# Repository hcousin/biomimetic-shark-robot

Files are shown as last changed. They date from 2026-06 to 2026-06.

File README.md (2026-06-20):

# Biomimetic Shark Robot — Hybrid Passive Tail Edition

**Naturgetreuer Haifisch-Roboter mit exzentrischer Nockenwelle (J1/J2 aktiv) + passiven TPU-Federgelenken (J3/J4)**

> 🌿 **Branch:** `dev/hybrid-passive-tail` — Hybrid-Design
> 📦 **main:** 4× aktive Gelenke (älteres Design)

---

## 📋 Projektübersicht

Ein biomimetischer Unterwasser-Roboter in Haiform (60 cm Länge), der mit **nur 1 Brushless-Motor** eine natürliche Schwimmbewegung erzeugt. Die kurze exzentrische Nockenwelle (60mm) treibt J1+J2 aktiv an — J3+J4 sind passive TPU-Federgelenke, die durch Trägheit und Wasserkräfte natürlich nachschwingen. Biologisch authentischer als 4× aktive Gelenke!

**Kernfeatures:**
- ✅ Hybrid-Antrieb: J1/J2 aktiv (Nockenwelle) + J3/J4 passiv (TPU-Feder)
- ✅ 1× Brushless Motor KV=900 (effizient, wasserdicht)
- ✅ Kurze Nockenwelle 60mm (günstiger, kompakter)
- ✅ Progressive Amplituden: J1 ±5.7° → J2 ±6.9° → J3 ~±10° → J4 ~±15°
- ✅ Passive Resonanz: J3 ≈ 1.0 Hz, J4 ≈ 0.8 Hz
- ✅ Tiefenregelung (PID + Ballast)
- ✅ IMU-Feedback (Brustflossen-Pitch)
- ✅ WiFi + Serial-Steuerung
- ✅ Fusion 360 Workflow: Haifisch-Körperhülle + Verbindungsflansch

---

## 📁 Dateistruktur

```
biomimetic-shark-robot/
├── README.md                                   ← Du bist hier
├── firmware/
│   ├── shark_single_motor_firmware.ino         ← ESP32 Hauptcode
│   └── nocke_kinematik.py                      ← Hybrid-Kinematik-Simulator
├── mechanics/
│   ├── hybrid_passive_tail_mechanics.md        ← Hybrid-Design Dokumentation ★
│   └── single_motor_mechanics.md               ← Referenz (4× aktiv, älter)
├── hardware/
│   └── bom_complete.csv                        ← Stückliste (Hybrid-Design)
├── cad/
│   ├── body_to_j1_flange.scad                  ← Verbindung Körper → J1 ★
│   ├── tail_link_parametric.scad               ← Gelenk-Flansche J1/J2 ★
│   ├── tpu_joint_j3.scad                       ← Passiver Federblock J3 ★
│   ├── tpu_joint_j4.scad                       ← Passiver Federblock J4 ★
│   ├── tail_link_j1.scad                       ← J1 OpenSCAD (Referenz)
│   ├── body_front.scad                         ← Hauptgehäuse
│   ├── silikon_form_flosse.scad                ← Silikonform Schwanzflosse
│   └── stl/                                    ← Exportierte STL-Dateien
├── docs/
│   ├── 3d_print_structure.md                   ← 3D-Druck Parameter (Hybrid)
│   ├── rf_underwater/rf_physics.md             ← RF-Physik Unterwasser
│   ├── silicone_molding_guide.md               ← Silikonabguss-Anleitung
│   └── strouhal_optimizer.py                   ← Hydrodynamik-Optimierer
├── schematics/
│   └── schaltplan_v2.svg                       ← Schaltplan ESP32
└── LICENSE
```

---

## 🚀 Schnelleinstieg

### Hardware-Voraussetzungen
- ESP32 DevKit v1
- Brushless Outrunner Motor (KV=900) + ESC 20A
- Nockenwelle Edelstahl Ø12×**60mm**, e=3mm (Dreherei ~20 CHF)
- 2× Gelenk-Flansche J1/J2 (PETG, aus `tail_link_parametric.scad`)
- 2× TPU-Federblöcke J3/J4 (TPU 95A + 85A, aus `tpu_joint_j3/j4.scad`)
- Verbindungsflansch Körper→J1 (`body_to_j1_flange.scad`)
- Wasserdichte Sensoren (MS5837, MPU6050)
- LiPo 3S Akku

### Firmware flashen
```bash
# Arduino IDE, Board: ESP32 DevKit v1
# Datei: firmware/shark_single_motor_firmware.ino
```

### Kinematik simulieren
```bash
python3 firmware/nocke_kinematik.py
# Zeigt aktive J1/J2 + passive J3/J4 Simulation über mehrere Zyklen
```

### OpenSCAD → STL (für Fusion 360)
```bash
# 1. OpenSCAD installieren: openscad.org
# 2. Datei öffnen, F6 (Render), dann Export as STL
# 3. In Fusion 360: Insert → Insert Mesh
```

---

## 🔧 Mechanik-Highlights

### Aktive Nockenwelle (J1 + J2)
```
Nockenwelle: Edelstahl Ø12×60mm, e=3mm
Gleitschuhe: 2× (0° und 90° versetzt)

J1 @ 0°:  L=30mm → arcsin(3/30) ≈ ±5.7°  (Kopf-nah)
J2 @ 90°: L=25mm → arcsin(3/25) ≈ ±6.9°  (Vordermitte)
```

### Passive TPU-Gelenke (J3 + J4)
```
J3: TPU 95A, 25% Infill → f_res ≈ 1.0 Hz → ~±10° bei Resonanz
J4: TPU 85A, 20% Infill → f_res ≈ 0.8 Hz → ~±15° bei Resonanz

Federstahl-Einlage 0.3mm empfohlen (verhindert Überdehnung)
```

### Phasenversätze (automatisch, mechanisch)
```
J1: θ₁(t) = 5.7°  · sin(2πf·t)
J2: θ₂(t) = 6.9°  · sin(2πf·t − π/2)
J3: θ₃(t) ≈ 10°   · sin(2πf·t − π)      ← passiv, resonanzverstärkt
J4: θ₄(t) ≈ 15°   · sin(2πf·t − 3π/2)   ← passiv, maximale Amplitude
```

---

## 📊 Performance-Daten

| Throttle | Motor RPM | Nocken Hz | Geschw. est. |
|---|---|---|---|
| 10% | ~1000 | 0.4 Hz | ~0.08 m/s |
| 25% | ~2500 | 1.0 Hz | ~0.22 m/s ← J3 Resonanz! |
| 20% | ~2000 | 0.8 Hz | ~0.18 m/s ← J4 Resonanz! |
| 50% | ~5000 | 2.1 Hz | ~0.44 m/s |

---

## 🛠️ Montage-Reihenfolge

1. **Kurze Nockenwelle** (60mm, Dreherei)
2. **Motor + Getriebe** (unverändert)
3. **Nur 2 Gleitschuhe** @ 0° + 90°
4. **J1 + J2 Flansche** an Zug-Stoß-Stangen
5. **TPU-Blöcke J3 + J4** einkleben (Silikonkleber, 24h)
6. **Verbindungsflansch** (`body_to_j1_flange.scad`) → Fusion 360 anpassen
7. **Elektronik** + Sensoren in Gehäuse
8. **Wassertest** bei 25% Throttle

---

## 🐟 Fusion 360 Workflow (Körperhülle)

```
1. Haifisch-Körper (OBJ) laden von Free3D / GrabCAD
2. Skalieren auf 60cm Länge
3. Schwanz bei ~60% Körperlänge abschneiden (Plane Cut)
4. Shell: 3mm Wandstärke
5. body_to_j1_flange.stl importieren (aus body_to_j1_flange.scad)
6. An Schnittstelle ausrichten → Combine → Join
7. Als STEP exportieren
```

Parameter in `body_to_j1_flange.scad` anpassen:
- `body_w` / `body_h` → Rumpf-Querschnitt an Schnittstelle (in Fusion messen)

---

## 📡 Steuerung

```
WiFi UDP:   "THROTTLE 0.25"  → 25% (J3-Resonanz!)
            "DEPTH 1.0"      → Tauchen auf 1m
            "SURFACE"        → Auftauchen
            "STOP"           → Notfall-Stopp

Serial:     throttle 0.25 | depth 1.0 | status | ?
```

---

## 💰 Kosten (Hybrid-Design)

| Kategorie | Kosten |
|---|---|
| Motor + ESC + Getriebe | ~73 CHF |
| Nockenwelle (kurz, 60mm) | ~20 CHF |
| Elektronik + Sensoren | ~74 CHF |
| 3D-Druck Material | ~66 CHF |
| Silikon + Formen | ~103 CHF |
| Dichtung + Kleinteile | ~65 CHF |
| **TOTAL** | **~458 CHF** |

---

## 📚 Dokumentation

| Datei | Inhalt |
|---|---|
| `mechanics/hybrid_passive_tail_mechanics.md` | Vollständige Mechanik-Spezifikation |
| `docs/3d_print_structure.md` | 3D-Druck Parameter + STL-Liste |
| `docs/silicone_molding_guide.md` | Silikonabguss-Anleitung |
| `firmware/nocke_kinematik.py` | Hybrid-Kinematik-Simulator |
| `docs/rf_underwater/rf_physics.md` | RF-Physik + Tether-Empfehlung |

---

## ⚠️ Sicherheitshinweise

- ⚠️ **Nockenwelle rotiert schnell** — vollständig abdecken!
- ⚠️ **TPU-Blöcke vor Wassertest** auf Klebefestigkeit prüfen
- ⚠️ **Wasserdichtheit prüfen** vor dem Eintauchen (Drucktest)
- ⚠️ **LiPo in feuerfester Box** laden

---

## 📖 Lizenz

MIT License — Frei nutzbar, Änderungen erlaubt, Nennung erforderlich.

---

**Status:** ✅ Hybrid-Design vollständig dokumentiert (Stand: Juni 2026)
**Branch:** `dev/hybrid-passive-tail` | PR #2 offen
**Schwierigkeitsgrad:** ⭐⭐☆☆☆ Einfacher als 4× aktives Design!

---

**Happy Shark Building! 🦈**

---

## 🔬 Acknowledgements & Related Work

Dieses Projekt ist eine unabhängige Reimplementierung, inspiriert durch folgende Open-Source-Arbeiten:

### OpenFish (TU Delft, 2022)
> van den Berg, S.C., Scharff, R.B.N., Rusák, Z., Wu, J. (2022).
> *OpenFish: Biomimetic Design of a Soft Robotic Fish for High Speed Locomotion.*
> HardwareX. https://doi.org/10.17605/OSF.IO/FB5VH
> **Lizenz: CC-BY-SA 4.0**

Konzeptuelle Inspiration: Kombination aus aktivem und passivem Schwanzsegment
für Thunniform-Schwimmen — in diesem Projekt neu implementiert mit
exzentrischer Nockenwelle + TPU-Federgelenken.

⚠️ **Hinweis:** Es wurden **keine Designdateien von OpenFish direkt übernommen**.
Dieses Projekt ist eine eigenständige Neuentwicklung mit anderer Hardware
(Brushless-Motor, exzentrische Nockenwelle, TPU-Gelenke, ESP32).
Die MIT-Lizenz dieses Projekts gilt daher uneingeschränkt.

### FISHR — Erweiterung von OpenFish (2025)
> *Fluid interaction study: Hydrodynamic robot (FISHR) —
> Expansion of bioinspired soft robotic fish.*
> HardwareX. https://www.hardware-x.com/article/S2468-0672(25)00052-5
> **Lizenz: CC BY 4.0**

Referenz für Validierungsmethodik (Tail-Kinematik-Vergleich, Strouhal-Optimierung).

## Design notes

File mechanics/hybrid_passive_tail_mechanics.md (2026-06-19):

# Hybrid-Antrieb: Aktive Nockenwelle (J1/J2) + Passive TPU-Gelenke (J3/J4)

## Konzept-Übersicht

```
Brushless Motor (KV=900)
        ↓
Getriebe 40:1
        ↓
Kurze Nockenwelle (nur ~60mm, 2 Gleitschuhe)
        ↓
2 Zug-Stoß-Stangen
        ↓
J1 (L=30mm, aktiv) ──→ J2 (L=25mm, aktiv)
                              ↓
                        J3 (TPU, passiv) ──→ J4 (TPU, passiv)
                        [Federeffekt]         [Federeffekt]
```

**Prinzip:**
- J1 + J2 werden **aktiv** von der Nockenwelle angetrieben
- J3 + J4 sind **passive TPU-Federgelenke** — sie schwingen durch die
  Trägheit und Wasserkräfte natürlich nach, wie der echte Schwanzbereich
  eines Hais

---

## Warum das biologisch überzeugend ist

Echte Haie (Carangiform/Thunniform-Schwimmer) haben:
- **Vorderkörper:** Aktive Muskulatur, kontrollierte Bewegung
- **Peduncle (Schwanzstiel):** Steife Sehnen, passive Kraftübertragung
- **Schwanzflosse:** Passiv elastisch, schwingt durch Hydrodynamik nach

→ Unser Hybrid-Design imitiert genau das:

| Bereich | Natur | Unser Roboter |
|---|---|---|
| Vorderkörper | Aktive Muskeln | Nockenwelle J1/J2 |
| Schwanzstiel | Steife Sehnen | TPU J3 (mittelharte Feder) |
| Schwanzflosse | Passiv elastisch | TPU J4 (weiche Feder) |

---

## Mechanik-Details

### Aktive Nockenwelle (J1 + J2)

```
Nockenwelle: Edelstahl, Ø12mm × 60mm (NUR 60mm — viel kürzer!)
Exzentrizität: e = 3mm
Gleitschuhe: 2 Stück (0° und 90° versetzt)

J1 @ 0°:  Hebel L₁ = 30mm → Amplitude arcsin(3/30) ≈ ±5.7°
J2 @ 90°: Hebel L₂ = 25mm → Amplitude arcsin(3/25) ≈ ±6.9°

Phasenversatz J1→J2: 90° (mechanisch durch Gleitschuh-Position)
```

**Vorteile kurze Nockenwelle:**
- Nur 60mm statt 120mm → passt leichter in den Rumpf
- Leichter, günstiger zu drehen (~20–25 CHF)
- Weniger Vibration
- Einfachere Lagerung (nur 2 Lagerbuchsen nötig)

### Passive TPU-Gelenke (J3 + J4)

```
Material:    TPU 95A (J3, mittelharte Feder)
             TPU 85A (J4, weiche Feder — mehr Nachschwingen)

Geometrie:   Kein separater Gelenk-Flansch mit Hebel!
             Stattdessen: Direkte TPU-Verbindung zwischen Segmenten

             Segment 2 ──[TPU-Block J3]── Segment 3
             Segment 3 ──[TPU-Block J4]── Schwanzflosse

TPU-Block-Maße:
  J3: 20 × 15 × 10mm, Shore 95A → ca. ±8–12° bei Wasserlast
  J4: 15 × 12 × 8mm,  Shore 85A → ca. ±12–18° bei Wasserlast

Federstahl-Einlage (optional):
  0.3mm × 8mm Federstahl-Streifen durch J4-Mitte
  → Gibt definierte Steifigkeit, verhindert zu weiches "Schlabbern"
```

**Passive Bewegung entsteht durch:**
1. Trägheit des Schwanzsegments bei Richtungsumkehr
2. Hydrodynamische Kräfte (Wasser drückt Flosse)
3. Rückstellkraft des TPU (Federwirkung)

→ Resultat: Natürlich ausschwingender Schwanz, ähnlich echtem Hai!

---

## Vergleich: Altes vs. neues Design

| Merkmal | Altes Design (4× aktiv) | Neues Design (2× aktiv + 2× passiv) |
|---|---|---|
| Nockenwellen-Länge | 120mm | **60mm** |
| Nockenwellen-Kosten | ~35 CHF | **~20 CHF** |
| Anzahl Gleitschuhe | 4 | **2** |
| Anzahl Zug-Stoß-Stangen | 4 | **2** |
| Gelenk-Flansche (komplex) | 4 | **2** |
| TPU-Blöcke (einfach) | 0 | **2** |
| Montage-Komplexität | ★★★★☆ | **★★☆☆☆** |
| Biologische Authentizität | ★★★★☆ | **★★★★★** |
| Kontrollierbarkeit | ★★★★★ | ★★★☆☆ |

---

## 3D-Druck: Neue Teile

### tpu_joint_j3.stl
```yaml
Funktion:    Passives Federgelenk zwischen Segment 2 und 3
Material:    TPU 95A
Maße:        20 × 15 × 10mm
Infill:      25% (weicher durch geringe Dichte)
Einlage:     Optional: 0.3mm Federstahl-Streifen (einlegen bei Z=5mm)
Montage:     Direkt zwischen Segment 2 + 3 eingeklebt (Silikongeklebt)
             oder mit 2× M2-Schrauben fixiert
Steifigkeit: ~0.08 N·mm/° (Schätzung, abhängig von Infill)
```

### tpu_joint_j4.stl
```yaml
Funktion:    Passives Federgelenk zwischen Segment 3 und Schwanzflosse
Material:    TPU 85A (weicher als J3!)
Maße:        15 × 12 × 8mm
Infill:      20% (sehr weich, maximales Nachschwingen)
Einlage:     0.3mm × 8mm Federstahl EMPFOHLEN (verhindert Überdehnung)
Montage:     Direkt an Schwanzflosse angeklebt
Steifigkeit: ~0.04 N·mm/° (sehr weich)
```

### nocken_kurz_halter.stl (AKTUALISIERT)
```yaml
Funktion:    Motorhalter + Nockenwellen-Lager (nur 60mm Welle)
Material:    PETG, 60% Infill
Änderung:   Lagerbuchsen jetzt nur 60mm auseinander (statt 120mm)
             → Kompakterer Halter, leichter
```

---

## Montagereihenfolge (Vereinfacht!)

1. **Kurze Nockenwelle vorbereiten** (Dreherei, ~20 CHF)
   - Ø12mm × 60mm, e=3mm
   - 2 Lager-Bohrungen (6001-2RS)

2. **Motor + Getriebe montieren**
   - Wie bisher (unverändert)

3. **Nur 2 Gleitschuhe + 2 Zug-Stoß-Stangen**
   - J1-Gleitschuh @ 0°
   - J2-Gleitschuh @ 90°
   - Schubstangen an Gelenk-Flansche J1/J2

4. **TPU-Blöcke einsetzen**
   - J3: TPU 95A zwischen Segment 2+3 einkleben
   - J4: TPU 85A zwischen Segment 3+Flosse einkleben
   - Federstahl-Einlage optional einlegen

5. **Test im Trockenen**
   - Aktive Gelenke: gleichmäßige Bewegung J1/J2?
   - Passive Gelenke: schwingen J3/J4 frei nach? (von Hand prüfen)

6. **Wassertest**
   - Bei 0.5 Hz: Schwanz sollte elegant nachschwingen
   - Bei 1.5 Hz: Schwanz schwingt mit, Amplitude wächst durch Resonanz

---

## Abstimmung der TPU-Steifigkeit

Die optimale Steifigkeit hängt von der Schwimmfrequenz ab.
Ziel: **Resonanzfrequenz der passiven Gelenke ≈ Schwimmfrequenz**

```
f_resonanz = (1/2π) × √(k/m)

k = Federsteifigkeit TPU [N·mm/°]
m = Trägheitsmoment Schwanzsegment [kg·mm²]

Für f_resonanz ≈ 1.0–1.5 Hz:
  → TPU 85A mit 20% Infill und ~5g Schwanzsegment: gut
  → Falls zu steif: Infill reduzieren oder TPU 75A verwenden
  → Falls zu weich: Infill erhöhen oder Federstahl-Einlage hinzufügen
```

---

## Kosten-Update

| Komponente | Altes Design | Neues Design |
|---|---|---|
| Nockenwelle | 35 CHF | **20 CHF** |
| Gleitschuhe (×2 statt ×4) | 4 CHF | **2 CHF** |
| Gelenk-Flansche (×2 statt ×4) | 4 CHF | **2 CHF** |
| TPU-Blöcke J3+J4 (neu) | — | **1 CHF** |
| **Ersparnis** | — | **~18 CHF** |

**Neues Total: ~460 CHF**

---

## Status

- ✅ Konzept definiert
- ⏳ nocke_kinematik.py anpassen (nur J1/J2 aktiv)
- ⏳ 3d_print_structure.md aktualisieren
- ⏳ OpenSCAD-Skript für TPU-Blöcke

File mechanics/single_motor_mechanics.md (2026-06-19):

# Biomimetic Haifisch — Hybrid-Antrieb: Aktive Nockenwelle (J1/J2) + Passive TPU-Gelenke (J3/J4)

> **Aktuelles Design** (Branch: `dev/hybrid-passive-tail`)
> Für das ältere 4× aktive Design: siehe Git-History

---

## Konzept-Übersicht

```
Brushless Outrunner Motor (KV=900, 20A ESC)
        ↓
Planetengetriebe 10:1 + Schneckengetriebe 4:1 = 40:1 total
        ↓
Kurze exzentrische Nockenwelle (Ø12mm × 60mm, e=3mm)
        ↓
2× Gleitschuh (0° und 90° versetzt)
        ↓
2× Zug-Stoß-Stange (Aluminium Ø6mm)
        ↓
J1 (aktiv, L=30mm) ──→ J2 (aktiv, L=25mm)
                               ↓
                         J3 (TPU 95A, passiv) ──→ J4 (TPU 85A, passiv)
                         [Feder + Dämpfung]         [Feder + Dämpfung]
                               ↓
                         Schwanzflosse (Silikon)
```

**Kernprinzip:**
- J1 + J2 werden **aktiv** durch die Nockenwelle angetrieben (kontrollierte Sinusbewegung)
- J3 + J4 sind **passive TPU-Federblöcke** — sie schwingen durch Trägheit und Wasserkräfte nach
- Progressive Amplituden entstehen automatisch: J1 < J2 < J3 < J4

---

## Nockenwelle: Design

### Geometrie

```
Nockenwelle (kurz, nur J1+J2):

  Länge:          60mm  (statt 120mm beim 4× aktiven Design)
  Außendurchm.:   Ø12mm
  Exzentrizität:  e = 3mm
  Gleitschuhe:    2× (bei 0° und 90°)

  Radius-Variation: R(θ) = R₀ + e·cos(θ)
    R₀ = 8mm (mittlerer Radius)
    e  = 3mm (Exzentrizität)
    → Max: 11mm, Min: 5mm
    → Linearer Hub: ±3mm
```

### Hebelarm → Gelenkwinkel

```
Gelenk-Formel: θ = arcsin(e / L)

J1: L=30mm → arcsin(3/30) ≈ ±5.7°   (Kopf-nah, sanfte Bewegung)
J2: L=25mm → arcsin(3/25) ≈ ±6.9°   (Vordermitte)

Phasenversatz J1→J2: 90° (durch Gleitschuh-Position)
```

### Material & Fertigung

| Komponente | Material | Abmessungen | Kosten |
|---|---|---|---|
| Nockenwelle | Edelstahl 1.4104 | Ø12mm × 60mm, e=3mm | ~20 CHF (Dreherei) |
| Gleitschuh ×2 | PETG/Nylon | 12×8mm | 3D-Druck |
| Zug-Stoß-Stangen ×2 | Alu 7075 | Ø6mm × 25mm | ~3 CHF |
| Kugellager 6001-2RS ×2 | Stahl | Ø12×28×8mm | ~6 CHF |

---

## Passive TPU-Gelenke (J3 + J4)

### Feder-Dämpfer-Modell

```
Jedes passive Gelenk verhält sich wie ein gedämpfter Schwinger:

  m·θ̈ + d·θ̇ + k·(θ - θ_input) = 0

  m = Trägheitsmoment Schwanzsegment
  d = Dämpfung (TPU-Material + Wasser)
  k = Federsteifigkeit (TPU-Infill + Shore)

Resonanzfrequenz: f_res = (1/2π) · √(k/m)
  J3 (TPU 95A, 25% Infill): f_res ≈ 1.0 Hz
  J4 (TPU 85A, 20% Infill): f_res ≈ 0.8 Hz
```

### Erwartete Amplituden im Betrieb

| Frequenz | J1 (aktiv) | J2 (aktiv) | J3 (passiv) | J4 (passiv) |
|---|---|---|---|---|
| 0.4 Hz | ±5.7° | ±6.9° | ~±4° | ~±6° |
| 0.8 Hz | ±5.7° | ±6.9° | ~±8° | **~±15°** ← J4 Resonanz! |
| 1.0 Hz | ±5.7° | ±6.9° | **~±10°** ← J3 Resonanz! | ~±12° |
| 1.5 Hz | ±5.7° | ±6.9° | ~±7° | ~±9° |

### TPU-Spezifikationen

```
J3 (tpu_joint_j3.scad):
  Material:   TPU 95A
  Maße:       20 × 15 × 10mm
  Infill:     25% Gyroid
  Federstahl: 0.3mm × 8mm Einlage bei Z=5mm

J4 (tpu_joint_j4.scad):
  Material:   TPU 85A  ← weicher!
  Maße:       15 × 12 × 8mm
  Infill:     20% Gyroid
  Federstahl: 0.3mm × 6mm Einlage, 3mm nach hinten versetzt
              → gibt Schwanzflosse natürlichen Anstellwinkel
```

---

## Brushless Motor & ESC

### Motorauswahl (unverändert)

```
Typ:        Outrunner Brushless KV=900
Leistung:   20–30W nominal
Spannung:   3S LiPo 11.1V
Strom:      2.5–3.5A nominal

Getriebe:   Planetengetriebe 10:1 + Schneckengetriebe 4:1 = 40:1 total
```

### RPM → Schwimmfrequenz

```
Nockenwellen-RPM = Motor-RPM / 40
Schwimmfrequenz  = Nockenwellen-RPM / 60

Throttle  Motor-RPM  Nocke-RPM  Frequenz  Empfehlung
  10%      ~1000       ~25       0.4 Hz    Langsam
  20%      ~2000       ~50       0.8 Hz    ← J4 Resonanz!
  25%      ~2500       ~62       1.0 Hz    ← J3 Resonanz! (Standard)
  50%      ~5000      ~125       2.1 Hz    Schnell
```

---

## Elektronik-Layout

```
LiPo 3S 11.1V
    │
    ├─→ [BEC 5V/3A] ──→ ESP32 + PCA9685 + Servos
    │
    └─→ [ESC 20A] ←──── PWM Pin 25 (ESP32)
         │
         └─→ Brushless Motor
              └─→ Getriebe 40:1
                   └─→ Nockenwelle (60mm)
                        ├─→ Gleitschuh J1 @ 0°  → Zug-Stoß-Stange → J1 (L=30mm)
                        └─→ Gleitschuh J2 @ 90° → Zug-Stoß-Stange → J2 (L=25mm)
                                                          ↓
                                                   TPU-Block J3 (95A)
                                                          ↓
                                                   TPU-Block J4 (85A)
                                                          ↓
                                                   Schwanzflosse (Silikon)

Freie Servo-Kanäle (PCA9685):
  CH0 → Brustflosse links
  CH1 → Brustflosse rechts
  CH2 → Ballast-Kolben
```

---

## Vergleich: 4× Aktiv vs. Hybrid

| Merkmal | 4× Aktiv (main) | Hybrid (dieser Branch) |
|---|---|---|
| Nockenwelle | 120mm, 35 CHF | **60mm, 20 CHF** |
| Gleitschuhe | 4× | **2×** |
| Zug-Stoß-Stangen | 4× | **2×** |
| Gelenk-Flansche (PETG) | 4× | **2×** |
| Passive Gelenke (TPU) | — | **2×** |
| Montage-Komplexität | ★★★★☆ | **★★☆☆☆** |
| Bio-Authentizität | ★★★★☆ | **★★★★★** |
| Kosten | 478 CHF | **458 CHF** |

---

## Montagereihenfolge

1. **Nockenwelle** (60mm) von Dreherei, 2× 6001-2RS Lager einpressen
2. **Motor + Getriebe** auf Motorhalter-Flansch montieren
3. **2× Gleitschuh** auf Nocke: J1 @ 0°, J2 @ 90°
4. **2× Zug-Stoß-Stange** an Gelenk-Flansche J1/J2 anschließen
5. **TPU-Block J3** zwischen Segment 2+3 einkleben (Silikonkleber, 24h)
6. **TPU-Block J4** zwischen Segment 3+Flosse einkleben (24h)
7. **Verbindungsflansch** (body_to_j1_flange) an Hai-Körperhülle anpassen
8. **Test trocken**: J1/J2 schwingen? J3/J4 nachgiebig + rückstellend?
9. **Wassertest**: Bei 25% Throttle (1.0 Hz) — J3 sollte in Resonanz mitschwingen

---

## Abstimmung TPU-Steifigkeit

Falls J3/J4 **zu steif** (kaum Bewegung):
- Infill reduzieren (15%)
- Shore-Wert senken (95A→85A für J3, 85A→75A für J4)
- Federstahl-Einlage weglassen

Falls J3/J4 **zu weich** (schlabbernd):
- Infill erhöhen (30%)
- Shore-Wert erhöhen
- Federstahl-Einlage dicker (0.5mm statt 0.3mm)

---

## CAD-Dateien

| Datei | Beschreibung |
|---|---|
| `cad/tail_link_parametric.scad` | Aktive Flansche J1 (L=30) + J2 (L=25) |
| `cad/tpu_joint_j3.scad` | Passiver Federblock J3 (TPU 95A) |
| `cad/tpu_joint_j4.scad` | Passiver Federblock J4 (TPU 85A) |
| `cad/body_to_j1_flange.scad` | Verbindung Hai-Körper → J1 |
| `cad/body_front.scad` | Hauptelektronikgehäuse |
| `cad/silikon_form_flosse.scad` | Negativform Schwanzflosse |

---

**Status:** 🟢 Konsistent mit Hybrid-Design
**Simulation:** `python3 firmware/nocke_kinematik.py`

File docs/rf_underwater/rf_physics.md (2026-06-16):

# RF-Signalübertragung unter Wasser — Physikalische Grundlagen

## Kernprinzip: Skin-Tiefe (Skin Depth)

Elektromagnetische Wellen werden in leitfähigen Medien (wie Wasser) exponentiell gedämpft.
Die charakteristische Eindringtiefe heißt **Skin-Tiefe δ**:

```
δ = 503 × √(ρ / f)

δ  = Skin-Tiefe [m]
ρ  = Spezifischer Widerstand des Wassers [Ω·m]
f  = Frequenz [Hz]
```

Die Signalamplitude fällt ab als:

```
A(d) = A₀ × e^(−d/δ)

Dämpfung in dB: L = 20 × log₁₀(e^(−d/δ)) = −8.686 × d/δ
```

### Wassertypen und Leitfähigkeit

| Wassertyp | ρ [Ω·m] | σ [S/m] |
|---|---|---|
| Destilliert | 10'000 | 0.0001  |
| Süßwasser (See)  | ~100 | ~0.01 |
| Brackwasser | ~10 | ~0.1 |
| Meerwasser | ~0.2 | ~5 |

---

## Frequenzvergleich (Süßwasser, ρ = 100 Ω·m)

| Frequenz | δ [m] | @0.5 m [dB] | @1.0 m [dB] | @2.0 m [dB] | Urteil |
|---|---|---|---|---|---|
| WiFi 2.4 GHz | 0.103 | −42  | −85  | −169 | ✗ Unbrauchbar |
| 433 MHz (LoRa) | 0.242 | −18  | −36  | −72  | ✗ Unbrauchbar |
| 27 MHz (RC) | 0.968 | −4.5 | −9 | −18  | ~ Grenzwertig |
| 3 MHz (HF) | 2.904 | −1.5 | −3 | −6 | ✓ Brauchbar |
| 300 kHz (LF) | 9.183 | −0.5 | −0.9 | −1.9 | ✓ Brauchbar |

**Faustregel:** Brauchbare Kommunikation erfordert d < 0.5 × δ (max. −8.7 dB).

---

## Warum 433 MHz für 1–2 m scheitert

Bei 433 MHz in Süßwasser: δ = 0.24 m

- Bei 1.0 m Tiefe: Dämpfung = −35.9 dB → Faktor 63× Signalverlust
- Bei 1.5 m Tiefe: Dämpfung = −53.9 dB → Faktor 500× Signalverlust

**Das Signal ist bei 1 m Tiefe praktisch nicht mehr vorhanden.**

---

## Lösungsoptionen für 1–2 m Tiefe

### Option 1: Tether-Kabel (Empfohlen ★★★★★)

```
Spezifikation:
  Kabel:      0.5 mm² 4-adrig, 5 m Länge
  Adern:      2× Strom (GND + 5 V) + 2× Daten (RS485)
  Protokoll:  RS485 / UART, 115200 Baud
  Kosten:     ~15 CHF
  Reichweite: bis 1200 m (RS485-Spezifikation)

Vorteile:
  - Zuverlässig bei jeder Tiefe
  - Niedrige Latenz (<1 ms)
  - Keine RF-Genehmigungen erforderlich
  - Stromversorgung möglich
  
Nachteil:
  - Kabel schränkt Bewegungsfreiheit ein
  - Kabelschleppwiderstand
```

### Option 2: 27-MHz-RC-Modul (Grenzwertig ★★★☆☆)

```
Frequenz:   27.095 MHz (CH1, CEPT-legal)
Skin-Tiefe: 0.97 m in Süßwasser
@1.0 m:     −9 dB → 35 % Signalstärke (grenzwertig)
@1.5 m:     −13.5 dB → 21 % Signalstärke (unzuverlässig)

Antenne:    λ/4 = 2.77 m Drahtantenne
            oder Ferritkern-Antennen (verkürzt)

Empfehlung: Nur für <0.8 m in Süßwasser zuverlässig
```

### Option 3: Hybrid WiFi + Autonomer Modus (★★★★☆)

```
Architektur:
  OBERFLÄCHE (0–0.2 m): WiFi UDP → volles Kommando
  TAUCHPHASE (>0.2 m):  Vorprogrammierte Mission
  
Ablauf:
  1. WiFi: Zieltiefe + Kurs setzen
  2. Hai taucht → WiFi-Signal reißt ab
  3. ESP32 führt gespeicherten Plan autonom aus
  4. Auftauchen → WiFi-Verbindung wiederhergestellt

Vorteil:   Kein Kabel
Nachteil:  Kein Echtzeit-Eingriff unter Wasser
```

### Option 4: Akustische Kommunikation (★★★★☆)

```
Medium:     Schallwellen (nicht RF!)
Frequenz:   20–200 kHz
@2 m:       < −1 dB (sehr gering)

Hardware:   Underwater Acoustic Modem
            z. B. Subnero M25M (~CHF 800)
            oder DIY: HC-SR04 + wasserdichte Piezo-Wandler

Vorteil:    Echtzeitkommunikation bis 100 m Tiefe
Nachteil:   Kosten, Komplexität, Latenz ~50 ms
```

---

## Empfehlung für dieses Projekt

**Für 1–2 m in Süßwasser (Pool/See):**

```
KURZFRISTIG:   Tether-Kabel (4-adrig, RS485)
               → Sofort funktionierend, CHF 15
              
MITTELFRISTIG: Hybrid-Ansatz
               → WiFi-Steuerung an Oberfläche
               → Autonome Tiefenfahrt nach Programm
               → Kein Kabel nötig
              
LANGFRISTIG:   Akustisches Modem (DIY)
               → Echte kabellose Steuerung bei Tiefe
```

---

## Anpassungen an der Firmware

Für den Hybrid-Ansatz benötigt die Firmware:
- Missionsspeicher (Tiefe + Kurs als Sequenz)
- WiFi-Verbindungsstatus-Erkennung
- Autonomen Fallback, wenn WiFi verloren

Für Tether:
- RS485-Transceiver (z. B. MAX485)
- Neuer UART-Handler in Firmware
- Einfaches ASCII-Protokoll: `T0.5` = Tiefe 0.5 m, `F0.6` = Throttle 60 %

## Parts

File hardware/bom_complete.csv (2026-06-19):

Kategorie | Bauteil | Beschreibung | Menge | Einheit | Kosten CHF | Lieferant | Bestellnr | Prio
Motor & Antrieb | Brushless Motor | Outrunner KV=900 20-30W Ø35mm | 1 | Stk | 18 | Banggood/Aliexpress | A2212-900KV | MUSS
Motor & Antrieb | ESC 20A | Hobbywing Platinum 20A mit BEC 5V/3A | 1 | Stk | 15 | Hobbywing | 30120300 | MUSS
Motor & Antrieb | Planetengetriebe 10:1 | Motorabgang 3mm auf 6mm | 1 | Stk | 22 | Aliexpress | Variiert | MUSS
Motor & Antrieb | Schneckengetriebe 4:1 | Modul 1 Schneckenrad + Welle | 1 | Set | 18 | Aliexpress | Variiert | MUSS
Mechanik | Nockenwelle KURZ | Edelstahl 1.4104 Ø12×60mm e=3mm GEDREHT (nur J1+J2!) | 1 | Stk | 20 | Lokale Dreherei | CNC-Custom | MUSS
Mechanik | Kugellager 6001-2RS | Ø12×28×8mm wasserdicht (Nockenwellen-Lager) | 2 | Stk | 6 | Conrad/Brütsch | 6001-2RS | MUSS
Mechanik | Kugellager 626-ZZ | Ø6×19×6mm für Gelenk-Flansche J1+J2 (2 je Gelenk) | 4 | Stk | 5 | Conrad/Brütsch | 626-ZZ | MUSS
Mechanik | Edelstahl-Achse Ø8mm | 1.4305 h6 Toleranz 200mm lang (2× Gelenk-Bolzen J1+J2) | 2 | Stk | 5 | Brütsch-Rüegger | D8H6 | MUSS
Mechanik | Zug-Stoß-Stangen Alu Ø6mm | 7075 Aluminium 25mm Länge (nur 2 Stück — J1+J2) | 2 | Stk | 3 | Modellbau | Selbst drehen | KANN
Mechanik | Gelenk-Flansch J1 (3D-Druck) | PETG Hebel L₁=30mm → ±5.7° — aktiv | 1 | Stk | 2 | Eigenproduktion | tail_link_j1.stl | MUSS
Mechanik | Gelenk-Flansch J2 (3D-Druck) | PETG Hebel L₂=25mm → ±6.9° — aktiv | 1 | Stk | 2 | Eigenproduktion | tail_link_j2.stl | MUSS
Mechanik | TPU-Federblock J3 (3D-Druck) | TPU 95A Shore — passives Federgelenk Hintermitte | 1 | Stk | 1 | Eigenproduktion | tpu_joint_j3.stl | MUSS
Mechanik | TPU-Federblock J4 (3D-Druck) | TPU 85A Shore — passives Federgelenk Schwanz | 1 | Stk | 1 | Eigenproduktion | tpu_joint_j4.stl | MUSS
Mechanik | Gleitschuh / Cam Follower (3D-Druck) | PETG — nur 2 Stück (nicht 4!) | 2 | Stk | 1 | Eigenproduktion | cam_follower.stl | MUSS
Mechanik | Federstahl-Streifen 0.3mm | Einlage in TPU-Blöcke J3+J4 (je 8mm + 6mm) | 2 | Stk | 2 | Modellbau/Uhrenmacher | Federstahl | KANN
Elektronik | ESP32 DevKit v1 | WiFi+BT Mikrocontroller 38-Pin | 1 | Stk | 8 | Aliexpress/Reichelt | ESP32-DEVKIT | MUSS
Elektronik | PCA9685 | I2C 16-Kanal Servo-Treiber | 1 | Stk | 6 | Aliexpress | PCA9685 | MUSS
Elektronik | MS5837-30BA | Drucksensor 300m IP68 I2C | 1 | Stk | 22 | Blue Robotics | Bar30 | MUSS
Elektronik | MPU-6050 | 6-DOF IMU Gyro+Accel I2C | 1 | Stk | 5 | Aliexpress | GY-521 | MUSS
Elektronik | Akku LiPo 3S | 11.1V 2200mAh 25C XT60 | 1 | Stk | 25 | Hobbyking | Variiert | MUSS
Elektronik | Ladegerät LiPo | Balance-Lader iMaxB6 oder ähnlich | 1 | Stk | 25 | Conrad | iMaxB6 | MUSS
Servo | MG90S wasserdicht | Brustflosse Links (3 kg·cm) | 1 | Stk | 7 | Aliexpress | DS3010 | MUSS
Servo | MG90S wasserdicht | Brustflosse Rechts (3 kg·cm) | 1 | Stk | 7 | Aliexpress | DS3010 | MUSS
Servo | MG996R wasserdicht | Ballast-Kolben (15 kg·cm) | 1 | Stk | 10 | Aliexpress | MG996R | MUSS
3D-Druck | PETG Filament 1kg | Körper + Gelenk-Flansche J1/J2 + Halter | 1 | Rolle | 30 | Prusa/Amazon | PETG-1KG | MUSS
3D-Druck | TPU 95A Filament 0.25kg | Federblock J3 + Dichtungsteile | 1 | Rolle | 12 | Aliexpress | TPU95A | MUSS
3D-Druck | TPU 85A Filament 0.25kg | Federblock J4 (weicher als J3!) | 1 | Rolle | 12 | Aliexpress | TPU85A | MUSS
3D-Druck | PLA 0.5kg | Nur für Silikonformen | 1 | Rolle | 12 | Variiert | PLA-Gray | KANN
Silikon | Dragon Skin 10 Fast 500g | Schwanzflosse + Körperhaut | 1 | Kit | 38 | Smooth-On/Amazon | DS10F-0.5 | MUSS
Silikon | Dragon Skin 10 Slow 500g | Brustflossen (flexibler) | 1 | Kit | 38 | Smooth-On/Amazon | DS10S-0.5 | KANN
Silikon | Mann Ease Release 200 | Trennmittel für Formen | 1 | Dose | 15 | Smooth-On | MER200 | MUSS
Silikon | Pigmente Set (blau/grau/schwarz) | Haifischfarben | 1 | Set | 12 | Smooth-On | Pigmente | KANN
Dichtung | O-Ring NBR 80×3mm | Hauptgehäuse Abdichtung | 5 | Stk | 8 | Brütsch-Rüegger | NBR-80-3 | MUSS
Dichtung | Marine Epoxy West System | Kabeldurchführungen + TPU-Blöcke verkleben | 1 | Kit | 22 | Baumarkt | 105/206 | MUSS
Dichtung | Silikonkleber transparent | TPU-Federblöcke J3+J4 an Segmente kleben | 1 | Tube | 8 | Baumarkt/Brütsch | Sika-221 | MUSS
Dichtung | JST-SM Stecker wasserdicht | Alle externen Kabelverbindungen | 10 | Set | 12 | Aliexpress | JST-SM | MUSS
Dichtung | Wellendichtring Simmerring 6×12×4 | Servo-Achsen-Durchführungen | 4 | Stk | 8 | Brütsch-Rüegger | TC-6-12-4 | MUSS
CFK | Carbon-Stab Ø3mm 300mm | Flossen-Verstärkung (Kern) | 2 | Stk | 8 | Hobbyking | CF-3-300 | MUSS
Kleinteile | Edelstahl-Schrauben Set M2/M3 | Diverse Längen (10-30mm) | 1 | Set | 10 | Brütsch-Rüegger | SS-SET | MUSS
Kleinteile | Silikagel Beutel 2g | Feuchtigkeitsschutz innen | 5 | Stk | 3 | Amazon | SG-2G | MUSS
Kleinteile | Kabelbinder sortiert | Kabelmanagement | 1 | Set | 4 | Baumarkt | Variiert | MUSS
TOTAL — main (4× aktiv) |  |  |  |  | 478
TOTAL — hybrid (2× aktiv + 2× passiv) |  |  |  |  | 458
EINSPARUNG |  |  |  |  | -20

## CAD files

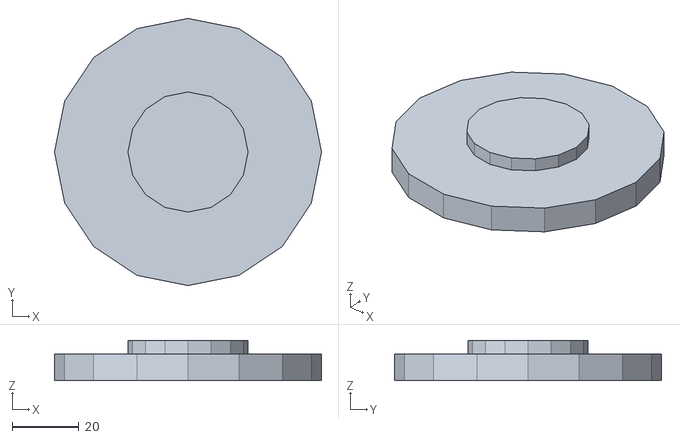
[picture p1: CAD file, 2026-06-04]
cad/motor_mount_flange.stl
80.0 x 80.0 x 12.0

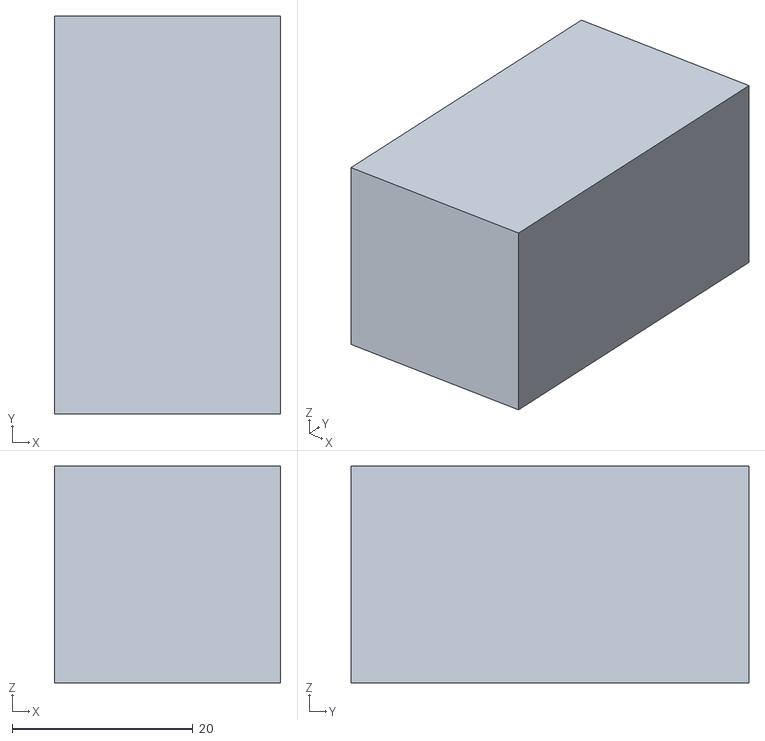
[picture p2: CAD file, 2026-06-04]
cad/stl/tail_link_j2.stl
25.0 x 44.0 x 24.0

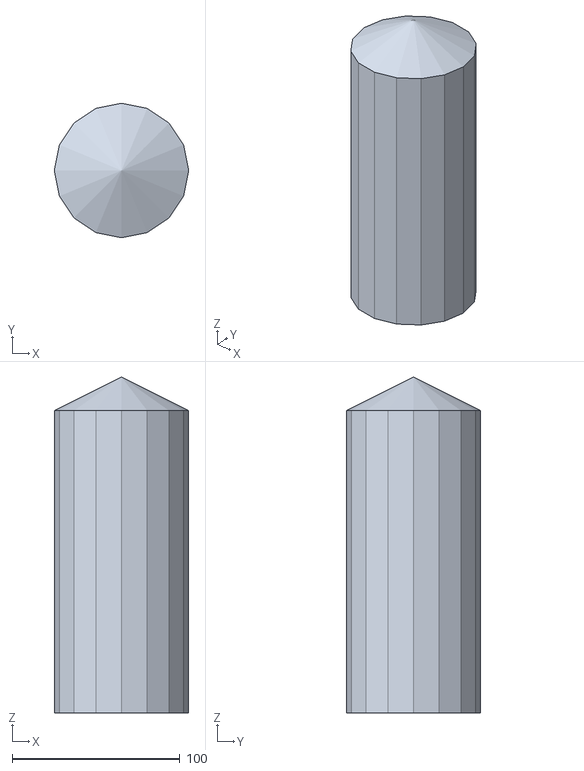
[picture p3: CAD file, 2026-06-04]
cad/body_front.stl
80.0 x 80.0 x 200.0

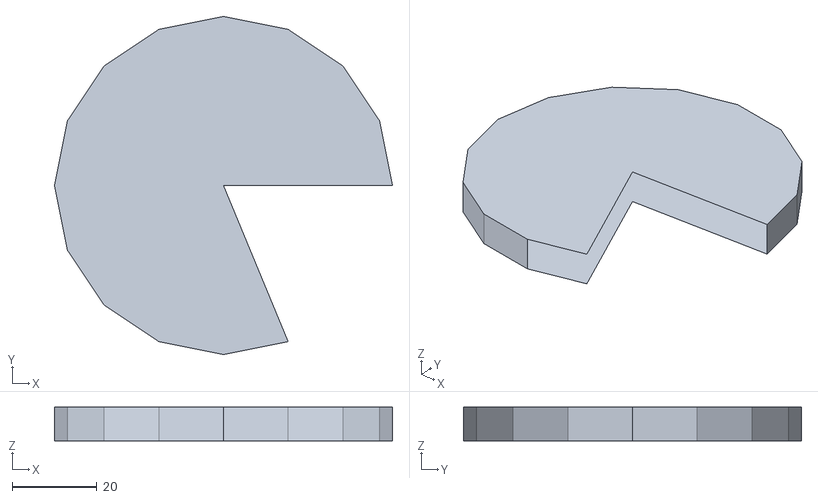
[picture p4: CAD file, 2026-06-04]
cad/body_lid_oring.stl
80.0 x 80.0 x 8.00

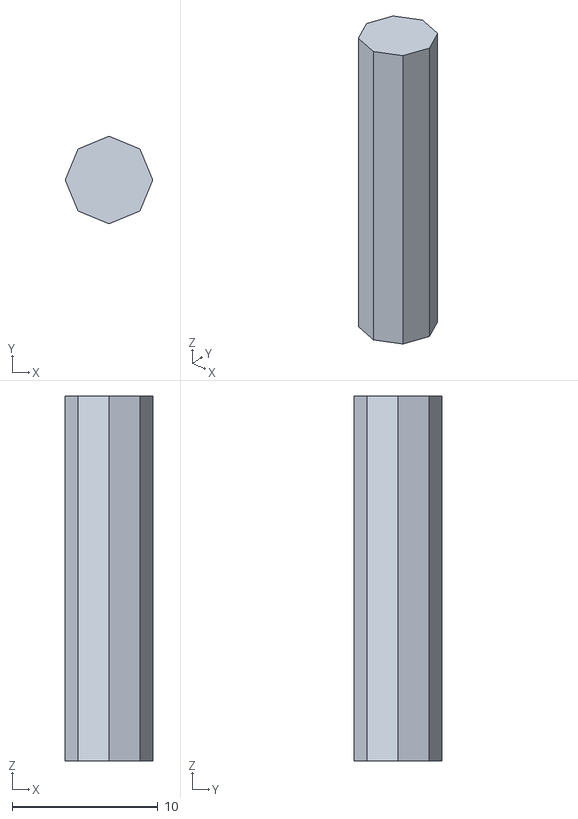
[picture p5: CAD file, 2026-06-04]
cad/crank_rod.stl
6.00 x 6.00 x 25.0

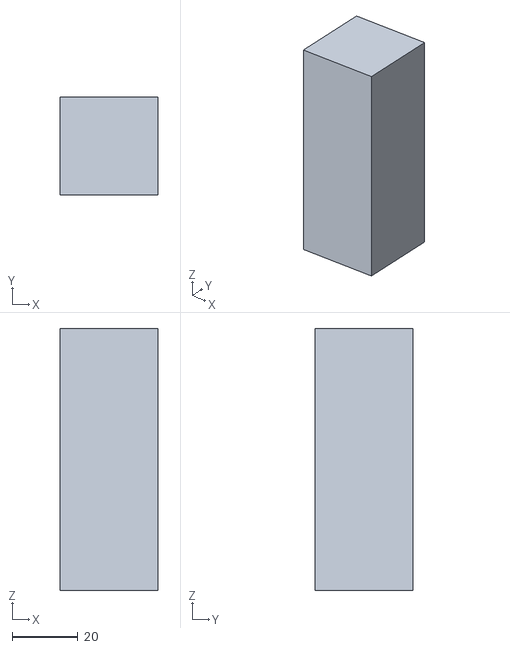
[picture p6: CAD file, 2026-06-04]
cad/ballast_syringe_holder.stl
30.0 x 30.0 x 80.0

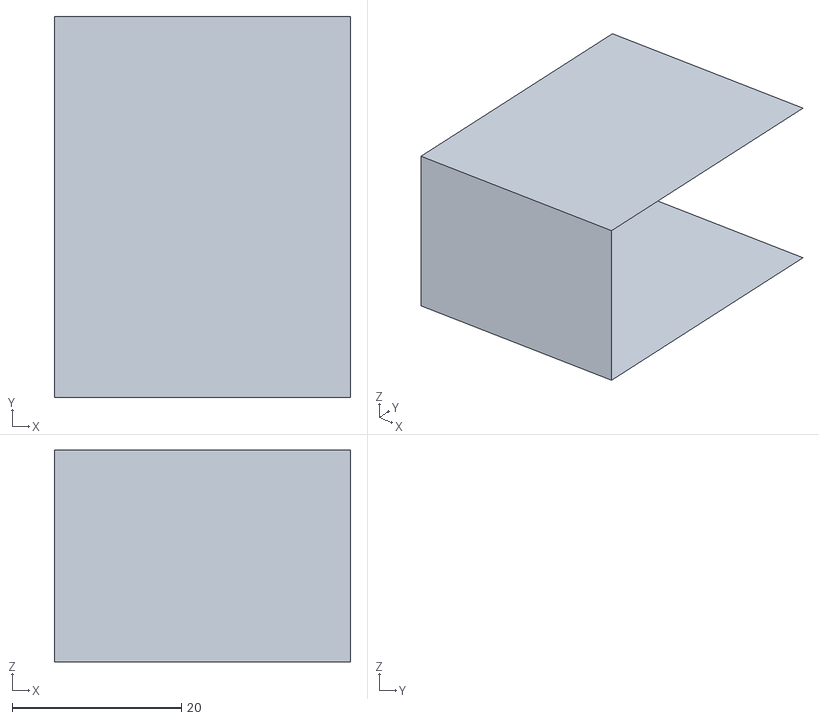
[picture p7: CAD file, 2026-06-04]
cad/servo_mount_j1.stl
35.0 x 45.0 x 25.0

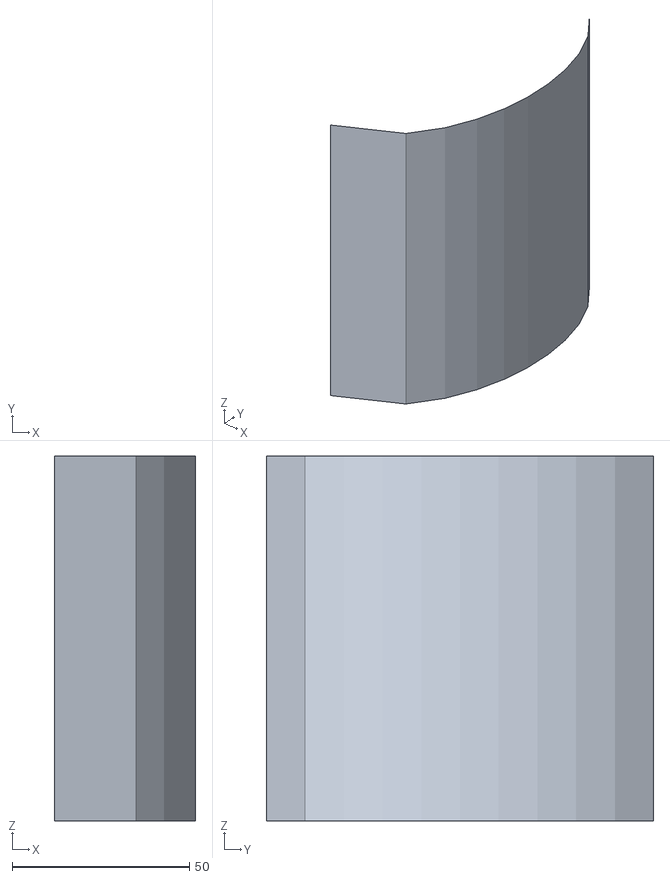
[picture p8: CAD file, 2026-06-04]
cad/silikon_form_flosse.stl
39.8 x 109.1 x 102.9

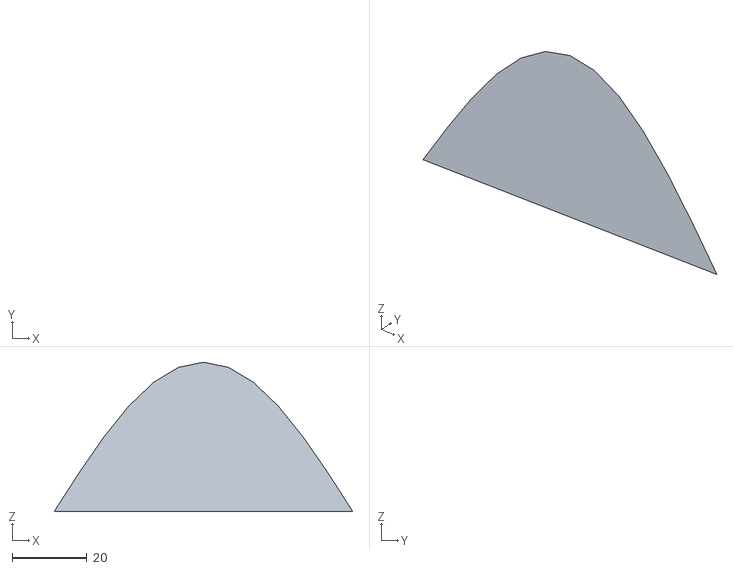
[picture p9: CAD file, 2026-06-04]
cad/dorsal_fin.stl
80.0 x 0 x 40.0

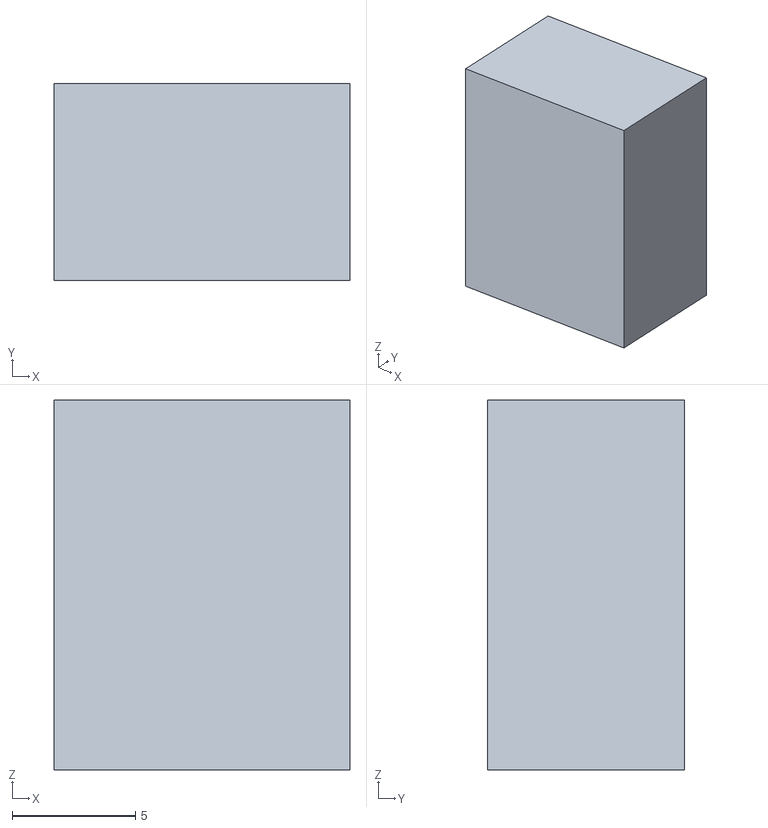
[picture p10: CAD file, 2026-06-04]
cad/cam_follower.stl
12.0 x 8.00 x 15.0

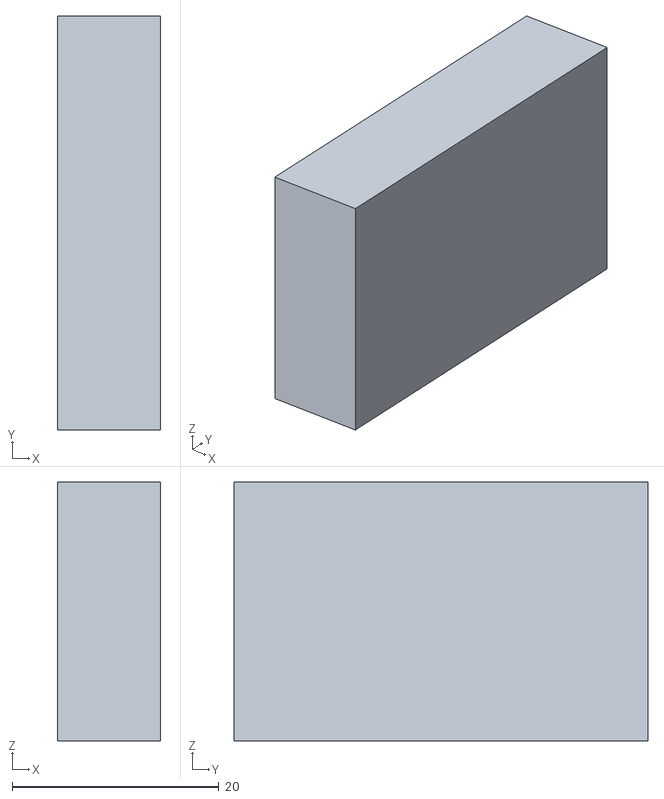
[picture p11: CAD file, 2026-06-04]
cad/pectoral_mount_left.stl
10.0 x 40.0 x 25.0

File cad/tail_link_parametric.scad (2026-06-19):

// ============================================================
//  tail_link_parametric.scad — Aktive Gelenk-Flansche J1 + J2
//  Erzeugt J1 (lever=30mm) oder J2 (lever=25mm)
//  Material: PETG, 50% Infill
// ============================================================

// ← Hier anpassen für J1 oder J2:
joint_name   = "J1";   // "J1" oder "J2"
lever_length = 30;     // J1=30mm, J2=25mm

// Berechnete Amplitude (nur Info):
// theta_max = arcsin(3mm / lever_length)
// J1: arcsin(3/30) ≈ 5.74°
// J2: arcsin(3/25) ≈ 6.89°

// Abmessungen
breite     = (lever_length == 30) ? 65 : 60;
tiefe      = (lever_length == 30) ? 40 : 38;
hoehe      = 20;
achse_r    = 4.1;   // Ø8.2mm für M8-Bolzen (leichtes Spiel)
lager_r    = 3.05;  // Ø6.1mm für 626-ZZ Kugellager
fase       = 1.5;

module gelenk_flansch(b, t, h, lever, achse_r, lager_r, fase) {
    difference() {
        // Hauptkörper
        hull() {
            for (x = [-b/2+fase, b/2-fase])
            for (y = [-t/2+fase, t/2-fase])
            for (z = [-h/2+fase, h/2-fase])
                translate([x, y, z]) sphere(r=fase, $fn=8);
        }

        // Zentrale Achsen-Bohrung (Ø8mm für M8-Bolzen)
        cylinder(h=h+1, r=achse_r, $fn=32, center=true);

        // Kugellager-Sitze beidseitig (626-ZZ, Ø6mm)
        for (y = [-t/2+2, t/2-2])
            translate([0, y, 0])
                cylinder(h=8, r=lager_r, $fn=24, center=true);

        // Zug-Stoß-Stangen-Anschluss (M6-Gewinde, am Hebelpunkt)
        translate([lever, 0, 0])
            cylinder(h=h+1, r=3.2, $fn=24, center=true);

        // Montagebohrungen zum Körper (2× M3)
        for (x = [-b/2+5, b/2-5])
            translate([x, 0, 0])
                cylinder(h=h+1, r=1.6, $fn=16, center=true);

        // Kabelkanal (Ø5mm, längs)
        translate([0, 0, 0])
            rotate([90, 0, 0])
                cylinder(h=t+1, r=2.5, $fn=16, center=true);
    }
}

gelenk_flansch(breite, tiefe, hoehe, lever_length, achse_r, lager_r, fase);

echo(str("Gelenk-Flansch ", joint_name, ": ", breite, "×", tiefe, "×", hoehe, "mm"));
echo(str("Hebel-Länge: ", lever_length, "mm"));
echo(str("Material: PETG | Infill: 50%"));

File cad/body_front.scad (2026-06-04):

// Biomimetic Shark Robot — Hauptelektronikgehäuse (Vorderteil)
// Material: PETG, 3D-Druck
// Parameter: 200mm Länge, Ø80mm, 3mm Wandstärke

$fn = 64;

// Parameter
length = 200;
outer_r = 40;
wall = 3;
oring_r = 3;
oring_depth = 2;
cable_hole_d = 8;

module main_body() {
    difference() {
        union() {
            cylinder(h=length-20, r=outer_r, $fn=$fn);
            translate([0, 0, length-20])
                sphere(r=outer_r, $fn=$fn);
        }
        union() {
            cylinder(h=length-wall-20, r=outer_r-wall, $fn=$fn);
            translate([0, 0, length-20])
                sphere(r=outer_r-wall, $fn=$fn);
        }
    }
}

module oring_groove() {
    rotate_extrude(angle=360, $fn=$fn)
        translate([outer_r - oring_r/2, wall + oring_depth/2])
            circle(r=oring_r/2, $fn=16);
}

module cable_port() {
    translate([outer_r-4, 0, 30])
        rotate([0, 90, 0])
            cylinder(h=10, r=cable_hole_d/2, $fn=16);
}

main_body();
oring_groove();
cable_port();

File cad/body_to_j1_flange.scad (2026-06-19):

// ============================================================
//  body_to_j1_flange.scad
//  Verbindungsflansch: Haifisch-Körper → Schwanzsegment J1
//
//  Zweck:
//    Schnittstelle zwischen dem importierten Hai-Körper (Fusion 360)
//    und dem ersten aktiven Gelenk-Flansch J1 (tail_link_j1.stl).
//
//  Workflow Fusion 360:
//    1. Dieses SCAD als STL exportieren (OpenSCAD → F6 → Export)
//    2. In Fusion 360: Insert → Insert Mesh → body_to_j1_flange.stl
//    3. Mit dem Hai-Körper (nach Shell) an der Schnittfläche ausrichten
//    4. Combine → Join
//    5. Gesamtes Modell als STEP exportieren (für Dreherei/Dokumentation)
//
//  Koordinatensystem:
//    +X = Schwanzrichtung (hinten)
//    -X = Kopfrichtung (vorne)
//    Z  = vertikal (oben)
// ============================================================

// ── Parameter ────────────────────────────────────────────────

// Körper-Querschnitt an der Schnittstelle (Hai-Rumpf, ~60% Länge)
body_w      = 55;    // mm Breite des Rumpfs an Schnittstelle
body_h      = 45;    // mm Höhe des Rumpfs an Schnittstelle
body_wall   = 3;     // mm Wandstärke Rumpf (aus Fusion 360 Shell)

// Flansch-Geometrie
flange_len  = 30;    // mm Länge des Übergangsstücks
flange_r    = 22;    // mm Aussenradius zylindrischer Zapfen (für J1)
j1_bore_r   = 4.1;  // mm Innenbohrung für M8-Achse (Gelenk J1)
j1_w        = 65;    // mm Breite J1-Flansch (aus tail_link_j1.stl)
j1_h        = 40;    // mm Höhe J1-Flansch

// Kabeldurchführung
cable_r     = 5;     // mm Radius Kabelkanal (ESP32-Kabel durch Gelenk)

// Schraubenlöcher (Flansch → Körper, M3)
screw_r     = 1.6;   // mm
screw_ring  = 28;    // mm Teilkreisradius der M3-Schrauben

// Fase / Übergang
fase        = 2.0;

// ── Hauptkörper ──────────────────────────────────────────────
module body_querschnitt(w, h, r=5) {
    // Abgerundetes Rechteck (Rumpf-Querschnitt)
    hull() {
        for (x = [-w/2+r, w/2-r])
        for (z = [-h/2+r, h/2-r])
            translate([x, 0, z]) circle(r=r, $fn=24);
    }
}

module flansch() {
    difference() {
        union() {
            // ① Übergangs-Extrusion: Rumpf-Querschnitt → Zylinder
            //    Linearer Übergang über flange_len
            hull() {
                // Rumpf-Seite (vorne, -Y)
                translate([0, 0, 0])
                    linear_extrude(height=1)
                        body_querschnitt(body_w, body_h);

                // Zapfen-Seite (hinten, +Y)
                translate([0, flange_len-1, 0])
                    linear_extrude(height=1)
                        circle(r=flange_r, $fn=48);
            }

            // ② Zylindrischer Zapfen für J1-Aufnahme
            translate([0, flange_len, 0])
                cylinder(h=18, r=flange_r, $fn=48);
        }

        // ── Subtraktionen ────────────────────────────────────

        // Innenhohlraum (Wandstärke body_wall)
        translate([0, -1, 0])
            linear_extrude(height=flange_len+2)
                body_querschnitt(body_w - 2*body_wall,
                                 body_h - 2*body_wall, r=3);

        // Zapfen-Innenbohrung (Kabelkanal + Achsbohrung)
        translate([0, flange_len-1, 0])
            cylinder(h=22, r=cable_r, $fn=24);

        // M8-Achsen-Bohrung für J1 (quer, X-Richtung)
        translate([0, flange_len+9, 0])
            rotate([0, 90, 0])
                cylinder(h=flange_r*3, r=j1_bore_r, $fn=24, center=true);

        // M3-Schrauben-Kranz (Flansch → Körper, 6× gleichmäßig)
        for (i = [0:5])
            rotate([0, 0, i*60])
                translate([screw_ring, 0, 0])
                    rotate([90, 0, 0])
                        cylinder(h=flange_len+5, r=screw_r, $fn=16);

        // Kabelkanal längs (ESP32-Kabel, Ø10mm)
        translate([0, -2, body_h/2 - body_wall - cable_r])
            rotate([-90, 0, 0])
                cylinder(h=flange_len+20, r=cable_r, $fn=24);
    }
}

// ── Render ───────────────────────────────────────────────────
flansch();

// ── Info ─────────────────────────────────────────────────────
echo("=== body_to_j1_flange.scad ===");
echo(str("Rumpf-Querschnitt: ", body_w, "×", body_h, "mm"));
echo(str("Zapfen-Radius:     ", flange_r, "mm (passt zu tail_link_j1.stl)"));
echo(str("M8-Achsbohrung:    Ø", j1_bore_r*2, "mm (quer, für Gelenk J1)"));
echo(str("Kabelkanal:        Ø", cable_r*2, "mm längs + quer"));
echo(str("M3-Schrauben:      6× auf Ø", screw_ring*2, "mm Teilkreis"));
echo("");
echo("Fusion 360 Workflow:");
echo("  1. OpenSCAD: F6 → Export als STL");
echo("  2. Fusion: Insert → Insert Mesh → body_to_j1_flange.stl");
echo("  3. Hai-Körper (nach Shell) an -Y-Fläche ausrichten");
echo("  4. Modify → Combine → Join");
echo("  5. File → Export → STEP (.step)");

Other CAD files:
cad/pectoral_mount_right.stl
cad/silikon_form_flosse.scad
cad/openscad/silikon_form_flosse.scad
cad/openscad/tail_link_j1.scad
cad/stl/pectoral_mount_right.stl
cad/tail_link_j1.scad
cad/tpu_joint_j3.scad
cad/tpu_joint_j4.scad

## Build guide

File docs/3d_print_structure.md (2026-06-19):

# 3D-Druckdateien-Struktur: Hybrid-Design (Aktive J1/J2 + Passive J3/J4)

> **Branch:** `dev/hybrid-passive-tail`
> **Design:** Kurze Nockenwelle (60mm) für J1+J2 aktiv, TPU-Federblöcke für J3+J4 passiv

---

## Dateistruktur

```
shark_robot/
├── body/
│   ├── body_front.stl             ← Vorderer Elektronikrumpf (unverändert)
│   ├── body_mid.stl               ← Mittelteil (unverändert)
│   ├── body_lid_front.stl         ← Deckel vorne (unverändert)
│   └── ballast_cylinder.stl       ← Ballastzylinder (unverändert)
├── tail/
│   ├── tail_link_j1.stl           ← Aktiver Gelenk-Flansch J1 (L=30mm)
│   ├── tail_link_j2.stl           ← Aktiver Gelenk-Flansch J2 (L=25mm)
│   ├── tpu_joint_j3.stl           ← Passiver TPU-Federblock J3 (Shore 95A)
│   ├── tpu_joint_j4.stl           ← Passiver TPU-Federblock J4 (Shore 85A)
│   ├── cam_follower.stl           ← Gleitschuh (×2 identisch, nicht ×4!)
│   └── crank_rod.stl              ← Zug-Stoß-Stange (×2 identisch)
├── fins/                          ← Unverändert
├── molds/                         ← Unverändert
└── misc/
    ├── nocken_halter_kurz.stl     ← NEU: Motorhalter für 60mm Nockenwelle
    ├── cable_guide.stl            ← Unverändert
    ├── imu_mount.stl              ← Unverändert
    └── depth_sensor_port.stl      ← Unverändert
```

---

## 🔴 Aktive Gelenke (Nockenwelle)

### tail_link_j1.stl — Aktives Gelenk J1 (Hebel L₁ = 30mm)

```yaml
Funktion:        Kopfnahes Gelenk, aktiv von Nockenwelle angetrieben
Hebel-Länge:     L₁ = 30mm → arcsin(3/30) ≈ ±5.7°
Maße:            65 × 40 × 20mm
Material:        PETG, 50% Infill
Achse:           Ø8mm Edelstahl-Bolzen (M8), 2× Kugellager 626-ZZ
Zug-Stoß-Punkt:  30mm von Gelenkachse
Montage:         An body_mid mit 2× M3-Schrauben
Druckzeit:       ~35 Min
```

### tail_link_j2.stl — Aktives Gelenk J2 (Hebel L₂ = 25mm)

```yaml
Funktion:        Zweites aktives Gelenk, 90° Phasenversatz zu J1
Hebel-Länge:     L₂ = 25mm → arcsin(3/25) ≈ ±6.9°
Maße:            60 × 38 × 20mm
Material:        PETG, 50% Infill
Achse:           Ø8mm Edelstahl-Bolzen (M8), 2× Kugellager 626-ZZ
Zug-Stoß-Punkt:  25mm von Gelenkachse
Montage:         Kettenartig nach J1
Druckzeit:       ~30 Min
```

---

## 🟢 Passive Gelenke (TPU-Federblöcke)

> Keine separaten Flansche mit Hebeln! Die Bewegung entsteht durch
> Trägheit + Wasserkräfte + TPU-Rückstellkraft — wie bei echten Haifischen.

### tpu_joint_j3.stl — Passiver Federblock J3

```yaml
Funktion:        Elastisches Verbindungsstück zwischen Segment 2 und 3
Material:        TPU 95A (mittelharte Feder)
Maße:            20 × 15 × 10mm
Infill:          25% Gyroid (weich, gleichmäßig)
Wandstärke:      1.2mm (3 Perimeter à 0.4mm)
Federstahl:      EMPFOHLEN: 0.3mm × 8mm Streifen bei Z=5mm einlegen
                 → Verhindert Überdehnung, definiert Mindeststeifigkeit
Montage:         Mit Silikonkleber zwischen Segment 2 + 3 einkleben
                 ODER 2× M2-Schrauben (Bohrungen im Block vorhanden)
Resonanz:        f_res ≈ 1.0 Hz → optimal bei ~25% Throttle
Erwartete Amp.:  ±8–10° bei 1.0 Hz Schwimmfrequenz
Druckzeit:       ~8 Min
Drucker:         ⚠️ Nur Direct-Drive-Extruder (kein Bowden für TPU!)
```

### tpu_joint_j4.stl — Passiver Federblock J4

```yaml
Funktion:        Elastisches Verbindungsstück zwischen Segment 3 und Schwanzflosse
Material:        TPU 85A (weicher als J3 — mehr Nachschwingen!)
Maße:            15 × 12 × 8mm
Infill:          20% Gyroid (sehr weich)
Wandstärke:      0.8mm (2 Perimeter à 0.4mm)
Federstahl:      EMPFOHLEN: 0.3mm × 6mm Streifen, leicht zur Hinterkante gebogen
                 → Gibt Schwanzflosse einen natürlichen Anstellwinkel
Montage:         Direkt an Schwanzflosse angeklebt (Epoxy oder Silikonkleber)
Resonanz:        f_res ≈ 0.8 Hz → leichtes Nachschwingen bei allen Frequenzen
Erwartete Amp.:  ±12–18° (Resonanzverstärkung bei ~0.8 Hz!)
Druckzeit:       ~5 Min
Drucker:         ⚠️ Nur Direct-Drive-Extruder (kein Bowden für TPU!)
```

---

## Vergleich: Altes Design vs. Hybrid

| Teil | Altes Design (4× aktiv) | Hybrid (2× aktiv + 2× passiv) |
|---|---|---|
| Nockenwelle | 120mm, 4 Gleitschuhe | **60mm, 2 Gleitschuhe** |
| Gelenk-Flansche | 4× PETG (komplex) | **2× PETG + 2× TPU (einfach)** |
| Zug-Stoß-Stangen | 4 Stück | **2 Stück** |
| Druckteile total | ~13 STL | **~11 STL** |
| Montage-Komplexität | ★★★★☆ | **★★☆☆☆** |
| Bio-Authentizität | ★★★★☆ | **★★★★★** |

---

## Druckparameter-Tabelle

| Teil | Material | Layer | Infill | Wände | Stützen | Zeit |
|---|---|---|---|---|---|---|
| tail_link_j1 | PETG | 0.20mm | 50% | 3 | Ja | 35 Min |
| tail_link_j2 | PETG | 0.20mm | 50% | 3 | Ja | 30 Min |
| **tpu_joint_j3** | **TPU 95A** | **0.25mm** | **25%** | **3** | Nein | **8 Min** |
| **tpu_joint_j4** | **TPU 85A** | **0.25mm** | **20%** | **2** | Nein | **5 Min** |
| cam_follower ×2 | PETG | 0.20mm | 50% | 3 | Nein | 5 Min je |
| crank_rod ×2 | PETG | 0.20mm | 50% | 3 | Nein | 10 Min je |
| nocken_halter_kurz | PETG | 0.20mm | 60% | 4 | Ja | 45 Min |

**Gesamtdruckzeit: ~10–12 Stunden** (kürzer als vorher!)

---

## Montagereihenfolge

1. **Kurze Nockenwelle** (60mm, Dreherei ~20 CHF)
   - 2× 6001-2RS Lager in `nocken_halter_kurz` einpressen
   - Motor + Getriebe montieren

2. **Aktive Gelenke J1 + J2**
   - 2× Gleitschuh @ 0° und 90° auf Nocke
   - 2× Zug-Stoß-Stangen an J1 + J2 Flansche anschließen
   - Test: Bewegen sich J1/J2 gleichmäßig mit 90° Versatz?

3. **Passive Gelenke J3 + J4** ← NEU, einfach!
   - Federstahl-Einlage bei Z=5mm in `tpu_joint_j3` einlegen
   - `tpu_joint_j3` zwischen Segment 2 + 3 mit Silikonkleber fixieren
   - 24h aushärten lassen
   - `tpu_joint_j4` an Schwanzflosse ankleben, 24h aushärten

4. **Test im Trockenen**
   - Motor bei 10% Throttle anfahren
   - J1/J2 sollten aktiv schwingen
   - J3/J4 von Hand prüfen: leicht biegbar, kehrt selbst zurück?

5. **Wassertest**
   - Bei 25% Throttle (~1.0 Hz): J3 sollte in Resonanz mitschwingen
   - Bei 20% Throttle (~0.8 Hz): J4 schwingt stärker (Resonanz J4!)
   - Schaut es wie ein echter Hai aus? ✓

---

## Abstimmung im Betrieb

Falls J3/J4 zu steif (wenig Bewegung):
- Infill reduzieren (z.B. 15%)
- TPU mit niedrigerem Shore-Wert (85A → 75A für J3)

Falls J3/J4 zu weich (schlabbernd):
- Infill erhöhen
- Federstahl-Einlage dicker (0.5mm statt 0.3mm)
- Shore-Wert erhöhen

---

## OpenSCAD-Skizze TPU-Federblock

```scad
// tpu_joint_parametric.scad
// Für J3: breite=20, tiefe=15, hoehe=10, shore=95
// Für J4: breite=15, tiefe=12, hoehe=8,  shore=85

breite = 20;
tiefe  = 15;
hoehe  = 10;

difference() {
    // Grundkörper
    cube([breite, tiefe, hoehe], center=true);

    // Montage-Bohrungen (2× M2)
    for (x = [-breite/4, breite/4])
        translate([x, 0, 0])
            cylinder(h=hoehe+1, r=1.1, $fn=16, center=true);

    // Federstahl-Kanal (bei Z=0, horizontal)
    translate([0, 0, 0])
        cube([breite+1, 1.0, 0.5], center=true);
}

// Info
echo(str("TPU-Block: ", breite, "×", tiefe, "×", hoehe, "mm"));
echo(str("Federstahl-Kanal bei Z=0 (Mitte)"));
```

---

## ✅ Konsistenz-Checkliste (Branch: dev/hybrid-passive-tail)

- ✅ `mechanics/hybrid_passive_tail_mechanics.md` — Konzept
- ✅ `firmware/nocke_kinematik.py` — J1/J2 aktiv, J3/J4 Feder-Simulation
- ✅ `docs/3d_print_structure.md` — TPU-Blöcke J3+J4 spezifiziert
- ⏳ OpenSCAD `.scad` Dateien für tpu_joint_j3 + j4
- ⏳ BOM aktualisieren (Branch-Version)

---

**Status:** 🟢 Hybrid-Design dokumentiert

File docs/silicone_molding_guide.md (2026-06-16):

# Silikonabguss-Anleitung: Haifisch-Haut & Schwanzflosse

## Überblick
Zwei separate Abgüsse:
1. **Schwanzflosse** (lunate, 12×8 cm) aus Dragon Skin 10 über CFK-Kern
2. **Körperhaut** (optionale Oberfläche) aus Dragon Skin 10 Slow, eingefärbt

---

## Teil 1: Schwanzflosse

### Materialien
| Material | Menge | Bezugsquelle |
|---|---|---|
| Dragon Skin 10 Fast (2-Komponenten) | 250 g Kit | Smooth-On / Amazon |
| Trennmittel (Mann 200) | 1 Dose | Smooth-On |
| CFK-Stab Ø 3 mm, 15 cm | 1 Stk. | Modellbauhandel |
| PLA-Filament (für Negativform) | ~50 g | — |
| Vakuumpumpe (optional) | — | Leihbar |
| Silikon-Pigment blau-grau | 2 ml | Smooth-On |

### Schritt 1: Negativform (3D-Druck)
Die Negativform wird in 2 Hälften gedruckt (Parting-Line entlang der Mittelebene der Flosse).

**Flosse Querschnitt (NACA-0010-Profil):**
- Gesamtspannweite: 120 mm (2× 60 mm Halbspannweite)
- Max. Chord: 80 mm
- Max. Dicke: 12 mm (10 % von 120 mm — NACA 0010)
- Lunate-Form: geschwungene Vorderkante, konkave Hinterkante

**STL-Form-Einstellungen:**
```
Layer Height:  0.2 mm (PETG)
Infill:        40 % (genug Steifigkeit gegen Silikondruck)
Walls:         4 Perimeter
Supports:      nein (Form muss aus 2 trennbaren Hälften bestehen)
Finish:        120er + 240er Schleifpapier, dann Epoxy-Coating
```

**CFK-Kern-Kanal:** Ø 3.5 mm Kanal entlang der Neutralachse, leicht nach vorne versetzt (30 % Chord) — wie bei echten Flossen-Calcifications.

### Schritt 2: Mischen & Einfärben
```
Dragon Skin 10 Fast:
  Part A : Part B = 1:1 nach Gewicht (z. B. 60 g : 60 g)
  Topf-Leben: ~3 Minuten (schnell arbeiten!)
  Aushärtung: 75 Minuten bei 23 °C

Pigmentierung (Blauhai-Grau):
  - 2 % Silikon-Pigment Blau: ~2.4 g auf 120 g Total
  - 0.5 % Schwarz: ~0.6 g
  → Ergibt: CMYK approx (85, 60, 30, 10) — typisches Haifisch-Rückengrau
```

### Schritt 3: Guss
1. Beide Formhälften mit Mann 200 Trennmittel einsprühen, 5 Min. trocknen lassen. Zweimal wiederholen.
2. CFK-Stab mit Klebeband temporär in Kanalposition halten.
3. Silikon mischen (s. o.), sofort in untere Formhälfte gießen — von einer Ecke aus, als Faden gießen, um Blasen zu vermeiden.
4. Obere Formhälfte auflegen, Schrauben M4 gleichmäßig anziehen (max. 2 N·m).
5. Optional: Vakuumkammer 2 Minuten bei −0.8 bar für blasenfreies Silikon.
6. 90 Minuten warten (Dragon Skin 10 Fast).
7. Vorsichtig öffnen — zuerst Schrauben, dann Formhälften auseinanderdrücken (nicht hebeln).
8. Flosse 24 Stunden nachaushärten lassen.

### Qualitätskontrolle
- Keine sichtbaren Blasen (bei Licht halten)
- CFK-Kern sitzt bei 25–35 % Chord
- Flossenflex-Test: leichtes Biegen ±30° ohne Delaminierung
- Wanddicke: 2–3 mm gleichmäßig

---

## Teil 2: Körperhaut (optional)

Die Körperhaut ist ein 2–3 mm dünner Silikonüberzug über dem 3D-gedruckten Rumpf. Sie verbessert die Optik und reduziert leicht die Grenzschichtstörung.

### Materialien
| Material | Menge |
|---|---|
| Dragon Skin 10 Slow | 500 g |
| Silikon-Pigmente (blau, grau, weiß) | je 5 ml |
| Slacker Softener (für Bauch-Region) | 50 ml |
| Pinsel 2 cm, Spachtel | — |

### Methode: Brush-On Skin
Statt Abguss wird die Haut direkt auf den Rumpf aufgepinselt (einfacher, weniger Abfall).

**Farbschema Weißer Hai / Blauhai:**
```
Rücken (dorsal):   DS10 + 3 % blau + 1 % schwarz + 0.5 % grün-grau
Flanke (lateral):  Übergangszone, trocken gemischt aus beiden
Bauch (ventral):   DS10 Slow + 20 % Slacker + 1 % weiß (leicht weicher)
```

**Aufbau (3 Schichten):**
1. Schicht: 1:1 mit Silikon-Thinner verdünnt → Grundierung, dünn aufpinseln. 30 Min.
2. Schicht: Unverdünnt, Rückenfarbe, 2–3 mm. 90 Min.
3. Schicht (Bauch): Verdünnte Weißmischung, weich überpinseln. 60 Min.

**Trennlinie**: Mit Klebeband entlang der Lateral-Linie abkleben vor Schicht 2/3.

**Oberflächenstruktur (optional):**
Durch Abrollen einer strukturierten PETG-Rolle (Haizahn-ähnliches Muster, 3D-gedruckt) auf der noch nicht ausgehärteten Schicht 2 lässt sich eine grobe Dentikel-Textur eindrücken.

---

## Teil 3: Brustflossen
Identische Methode wie Schwanzflosse, aber:
- Profil: NACA 0010, Spannweite 40 mm, Chord 25 mm
- CFK-Stab Ø 2 mm, leicht zur Hinterkante hin gebogen (5°)
- Material: DS10 Slow (flexibler, für Brustflosse wichtig)
- Einbettung: 2× M2-Messing-Insert für Servo-Verbindung an der Wurzel

---

## Sicherheitshinweise
- Dragon Skin Part A + B nie unvermischt auf die Haut bringen — Latexhandschuhe tragen
- Trennmittel gut belüften
- Vakuumpumpe: nie über −0.9 bar (Formverformung)
- Ausgussmaterial: Schwindung ~0 %, keine Nachkalibrierung nötig

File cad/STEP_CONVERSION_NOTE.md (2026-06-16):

# STEP-Format-Konvertierung

Die `.stl`-Dateien können zu echten STEP/STP-Dateien konvertiert werden mit:

## Kostenlose Tools

### FreeCAD (Empfohlen, Open Source)
1. FreeCAD installieren: https://www.freecad.org
2. Datei → Öffnen → `.stl`-Datei wählen
3. Datei → Export → `.step` wählen
4. Alle Teile als Assembly exportieren

### Online-Konverter
- https://www.freeconvert.com/stl-to-step
- https://cadexchanger.com/online/

### Python (CadQuery)
```python
import cadquery as cq
# STEP importieren/exportieren
shape = cq.importers.importStep("part.step")
cq.exporters.export(shape, "output.step")
```

## Warum STEP besser ist

| Format | Nutzen |
|---|---|
| STL | 3D-Druck, Rapid Prototyping |
| STEP/STP | CNC, Präzisionsfertigung, CAD-Austausch |
| GCODE | Direkt für 3D-Drucker/CNC |

Die Nockenwelle **muss** als STEP an die Dreherei gesendet werden!

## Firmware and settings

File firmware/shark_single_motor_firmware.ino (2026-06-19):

/*
 * ============================================================
 *  BIOMIMETISCHER HAIFISCH — HYBRID PASSIVE TAIL VERSION
 *  Exzentrische Nockenwelle + BL Motor (ESC) + Passive TPU Gelenke
 * ============================================================
 *
 *  Hardware (aus mechanics/hybrid_passive_tail_mechanics.md):
 *    - ESP32 DevKit
 *    - Brushless Outrunner Motor (KV=900)
 *    - ESC 20A mit PWM-Input
 *    - Exzentrische Nockenwelle: O12mm x 60mm, e=3mm (KURZ!)
 *    - 2 AKTIVE Gelenk-Flansche (Nockenwelle):
 *        J1: L=30mm -> +-5.7 deg (arcsin(3/30))
 *        J2: L=25mm -> +-6.9 deg (arcsin(3/25))
 *        Gleitschuhe: 2 Stueck @ 0 deg und 90 deg
 *    - 2 PASSIVE TPU-Federgelenke (KEINE Nockenwelle!):
 *        J3: TPU 95A, 20x15x10mm -> Resonanz @ 1.0 Hz, Amp: +-8-12 deg
 *        J4: TPU 85A, 15x12x8mm  -> Resonanz @ 0.8 Hz, Amp: +-12-18 deg
 *      Passive Bewegung durch: Traegheit + Hydrodynamik + TPU-Rueckstellkraft
 *    - 2x MG90S Brustflossen-Servo
 *    - 1x MG996R Ballast-Servo
 *    - MS5837-30BA Drucksensor
 *    - MPU-6050 IMU
 *
 *  Elektronik:
 *    GPIO 25 -> ESC PWM Input (50 Hz, 1000-2000 us)
 *    I2C 21/22 -> Sensoren (MS5837, MPU6050)
 *    SDA/SCL -> PCA9685 (optional fuer weitere Servos)
 *
 *  WICHTIG: Nur J1+J2 werden von der Nockenwelle angesteuert!
 *  J3+J4 sind PASSIV und schwingen durch:
 *    - Traegheit des Schwanzsegments bei Richtungsumkehr
 *    - Hydrodynamische Kraefte (Wasser drueckt Flosse)
 *    - Rueckstellkraft des TPU (Federwirkung)
 *  
 *  Der Code regelt nur:
 *    - Motor-Drehzahl (via ESC PWM)
 *    - Brustflossen-Pitch (IMU-Feedback)
 *    - Tiefe (Ballast-PID)
 *
 *  Die progressive Koerperwelle entsteht durch:
 *    - Mechanische Ansteuerung J1+J2 (Nockenwelle)
 *    - Passives Nachschwingen J3+J4 (TPU-Federn)
 *  -> Biologisch authentisch wie echter Hai!
 *
 *  Getriebe: 40:1 (10:1 Planetengetriebe x 4:1 Schneckengetriebe)
 *  Fur Kinematik-Simulation: siehe firmware/nocke_kinematik.py
 *  Branch: dev/hybrid-passive-tail
 * ============================================================
 */

#include <Wire.h>
#include <WiFi.h>
#include <WiFiUdp.h>

// --- Sensor-Adressen ---
#define MPU6050_ADDR   0x68
#define MS5837_ADDR    0x76

// --- ESC PWM Output ---
#define ESC_PIN        25
#define PWM_FREQ       50
#define PWM_RESOLUTION 16
#define PWM_CHANNEL    0

#define ESC_MIN_PWM    3276
#define ESC_MID_PWM    4915
#define ESC_MAX_PWM    6553

// --- Nockenwellen-Kinematik (Hybrid-Design: 2 aktiv + 2 passiv) ---
// KURZE Nockenwelle: O12mm x 60mm (nicht 120mm!), e=3mm Exzentrizitaet
// NUR 2 Gleitschuhe @ 0 deg und 90 deg (nicht 4!)
// AKTIVE Gelenke (Nockenwelle):
//   J1: Hebel L1=30mm -> arcsin(3/30) = +-5.7 deg (Kopf-nah)
//   J2: Hebel L2=25mm -> arcsin(3/25) = +-6.9 deg (Vordermitte)
//   Phasenversatz: J1 @ 0 deg, J2 @ 90 deg (mechanisch)
// PASSIVE Gelenke (TPU-Federblocke, KEINE Nockenwelle!):
//   J3: TPU 95A, 20x15x10mm -> Resonanz @ 1.0 Hz, Amp: +-8-12 deg
//   J4: TPU 85A, 15x12x8mm  -> Resonanz @ 0.8 Hz, Amp: +-12-18 deg
//   Bewegung durch: Traegheit + Hydrodynamik + TPU-Feder
// Getriebe: 40:1 (10:1 Planetengetriebe x 4:1 Schneckengetriebe)
// Nockenwellen-RPM = Motor-RPM / 40
// Schwimmfrequenz = Nockenwellen-RPM / 60
// Fur Simulation: siehe firmware/nocke_kinematik.py

// --- Motorsteuerung Parameter ---
struct MotorControl {
  float throttle      = 0.0f;
  float throttle_set  = 0.0f;
  float ramp_rate     = 0.1f;
  uint16_t pwm_out    = ESC_MIN_PWM;
  float rpm           = 0.0f;
  float freq_swim     = 0.0f;
} motor;

// --- Tiefenregler & Ballast ---
struct PIDState {
  float kp          = 1.4f;
  float ki          = 0.25f;
  float kd          = 0.08f;
  float setpoint    = 0.0f;
  float integral    = 0.0f;
  float prevError   = 0.0f;
  float output      = 0.0f;
} depthPID;

uint8_t ballastPos  = 90;

// --- Sensorwerte ---
float depthM        = 0.0f;
float pitchDeg      = 0.0f;
float rollDeg       = 0.0f;
float tempC         = 20.0f;

// --- MS5837 PROM ---
uint16_t ms5837_C[7] = {0};

// --- Brustflossen-Pitch-Korrektur ---
struct PectoralControl {
  float pitch_left   = 0.0f;
  float pitch_right  = 0.0f;
  float imr_damp     = 0.3f;
  float dive_offset  = 0.0f;
} pectoral;

// --- Zeitsteuerung ---
unsigned long lastSensor  = 0;
unsigned long lastPID     = 0;
unsigned long lastTelem   = 0;
const uint32_t SENSOR_DT_MS = 50;
const uint32_t PID_DT_MS    = 50;
const uint32_t TELEM_DT_MS  = 500;

bool emergencyStop = false;

// --- WiFi UDP ---
const char* WIFI_SSID  = "SharkControl";
const char* WIFI_PASS  = "haifisch2024";
WiFiUDP udp;
char udpBuf[256];

// ============================================================
//  MPU-6050
// ============================================================
void mpu_init() {
  Wire.beginTransmission(MPU6050_ADDR);
  Wire.write(0x6B); Wire.write(0x00);
  Wire.endTransmission();
}

void mpu_read() {
  Wire.beginTransmission(MPU6050_ADDR);
  Wire.write(0x3B); Wire.endTransmission(false);
  Wire.requestFrom(MPU6050_ADDR, 6, true);
  int16_t ax = (Wire.read()<<8)|Wire.read();
  int16_t ay = (Wire.read()<<8)|Wire.read();
  int16_t az = (Wire.read()<<8)|Wire.read();
  pitchDeg = atan2f((float)ay, (float)az) * 57.296f;
  rollDeg  = atan2f((float)ax, (float)az) * 57.296f;
}

// ============================================================
//  MS5837-30BA Drucksensor
// ============================================================
void ms5837_init() {
  Wire.beginTransmission(MS5837_ADDR);
  Wire.write(0x1E); Wire.endTransmission();
  delay(10);
  for (uint8_t i = 1; i <= 6; i++) {
    Wire.beginTransmission(MS5837_ADDR);
    Wire.write(0xA0 + i * 2);
    Wire.endTransmission();
    Wire.requestFrom(MS5837_ADDR, 2, true);
    ms5837_C[i] = ((uint16_t)Wire.read() << 8) | Wire.read();
  }
}

uint32_t ms5837_readADC(uint8_t cmd) {
  Wire.beginTransmission(MS5837_ADDR);
  Wire.write(cmd); Wire.endTransmission();
  delay(3);
  Wire.beginTransmission(MS5837_ADDR);
  Wire.write(0x00); Wire.endTransmission();
  Wire.requestFrom(MS5837_ADDR, 3, true);
  return ((uint32_t)Wire.read()<<16)|((uint32_t)Wire.read()<<8)|Wire.read();
}

void ms5837_read() {
  uint32_t D1 = ms5837_readADC(0x40);
  uint32_t D2 = ms5837_readADC(0x50);
  int32_t dT   = (int32_t)D2 - ((int32_t)ms5837_C[5] << 8);
  tempC        = 20.0f + dT * ms5837_C[6] / 8388608.0f;
  int64_t OFF  = ((int64_t)ms5837_C[2] << 16) + ((int64_t)ms5837_C[4] * dT >> 7);
  int64_t SENS = ((int64_t)ms5837_C[1] << 15) + ((int64_t)ms5837_C[3] * dT >> 8);
  float pressureMbar = ((D1 * SENS / 2097152.0f - OFF) / 32768.0f) / 100.0f;
  depthM = (pressureMbar - 1013.25f) / (1025.0f * 9.80665f / 100.0f);
  depthM = max(depthM, 0.0f);
}

// ============================================================
//  Motor ESC PWM Control
// ============================================================
void motor_init() {
  ledcSetup(PWM_CHANNEL, PWM_FREQ, PWM_RESOLUTION);
  ledcAttachPin(ESC_PIN, PWM_CHANNEL);
  ledcWrite(PWM_CHANNEL, ESC_MIN_PWM);
  delay(500);
}

void motor_update(float dt_s) {
  float diff = motor.throttle_set - motor.throttle;
  if (abs(diff) > 0.01f) {
    motor.throttle += constrain(diff, -motor.ramp_rate * dt_s, motor.ramp_rate * dt_s);
  } else {
    motor.throttle = motor.throttle_set;
  }
  motor.pwm_out = (uint16_t)(ESC_MIN_PWM + motor.throttle * (ESC_MAX_PWM - ESC_MIN_PWM));
  float motor_rpm = motor.throttle * 9990.0f;
  float nocke_rpm = motor_rpm / 40.0f;
  motor.freq_swim = nocke_rpm / 60.0f;
  ledcWrite(PWM_CHANNEL, motor.pwm_out);
}

// ============================================================
//  PID Tiefenregler
// ============================================================
void runDepthPID(float dt_s) {
  float error = depthPID.setpoint - depthM;
  depthPID.integral  += error * dt_s;
  depthPID.integral   = constrain(depthPID.integral, -5.0f, 5.0f);
  float derivative    = (error - depthPID.prevError) / dt_s;
  depthPID.prevError  = error;
  depthPID.output     = depthPID.kp * error
                      + depthPID.ki * depthPID.integral
                      + depthPID.kd * derivative;
  ballastPos = (int)constrain(90.0f + depthPID.output * 8.0f, 70.0f, 110.0f);
}

// ============================================================
//  Brustflossen-Steuerung (IMU-Feedback)
// ============================================================
void updatePectoralFins() {
  float pitch_corr = pitchDeg * pectoral.imr_damp;
  pectoral.pitch_left  = -pitch_corr + pectoral.dive_offset;
  pectoral.pitch_right = -pitch_corr + pectoral.dive_offset;
  pectoral.pitch_left  = constrain(pectoral.pitch_left, -25.0f, 25.0f);
  pectoral.pitch_right = constrain(pectoral.pitch_right, -25.0f, 25.0f);
}

// ============================================================
//  UDP Kommando-Parser
// ============================================================
void parseUDP() {
  int len = udp.parsePacket();
  if (!len) return;
  udp.read((uint8_t*)udpBuf, sizeof(udpBuf)-1);
  udpBuf[len] = 0;
  String s(udpBuf);
  s.toUpperCase();
  if (s.startsWith("THROTTLE ")) {
    motor.throttle_set = constrain(s.substring(9).toFloat(), 0.0f, 1.0f);
    Serial.print("Throttle set to: "); Serial.println(motor.throttle_set);
  }
  else if (s.startsWith("DEPTH ")) {
    depthPID.setpoint = constrain(s.substring(6).toFloat(), 0.0f, 10.0f);
    pectoral.dive_offset = -15.0f;
    Serial.print("Target depth: "); Serial.println(depthPID.setpoint);
  }
  else if (s == "SURFACE") {
    depthPID.setpoint = 0.0f;
    pectoral.dive_offset = 0.0f;
    Serial.println("Ascending...");
  }
  else if (s == "STOP") {
    motor.throttle_set = 0.0f;
    depthPID.setpoint = depthM;
    emergencyStop = true;
    Serial.println("EMERGENCY STOP");
  }
  else if (s == "GO") {
    emergencyStop = false;
    Serial.println("Resume");
  }
  char reply[128];
  snprintf(reply, sizeof(reply),
    "DEPTH:%.2f,PITCH:%.1f,MOTOR:%.1f%%,FREQ:%.2fHz",
    depthM, pitchDeg, motor.throttle*100.0f, motor.freq_swim);
  udp.beginPacket(udp.remoteIP(), udp.remotePort());
  udp.print(reply);
  udp.endPacket();
}

// ============================================================
//  Serial Debug Interface
// ============================================================
void parseSerial() {
  if (!Serial.available()) return;
  String s = Serial.readStringUntil('\n');
  s.trim();
  if (s == "status") {
    Serial.printf("DEPTH: %.2f m | PITCH: %.1f deg | TEMP: %.1f C\n", depthM, pitchDeg, tempC);
    Serial.printf("MOTOR: %.0f%% Throttle | Freq: %.2f Hz | RPM: %.0f\n",
                  motor.throttle*100.0f, motor.freq_swim, motor.throttle * 9990.0f);
    Serial.printf("Ballast: %d | Pect-L: %.1f deg | Pect-R: %.1f deg\n",
                  ballastPos, pectoral.pitch_left, pectoral.pitch_right);
    Serial.println("Gelenk-Amplituden (Hybrid-Design: 2 aktiv + 2 passiv):");
    Serial.println("  AKTIV (Nockenwelle): J1 (L=30mm): +-5.7 deg | J2 (L=25mm): +-6.9 deg");
    Serial.println("  PASSIV (TPU-Feder): J3 (95A): +-8-12 deg | J4 (85A): +-12-18 deg");
  }
  else if (s.startsWith("throttle ")) {
    motor.throttle_set = constrain(s.substring(9).toFloat(), 0.0f, 1.0f);
    Serial.println("Throttle OK");
  }
  else if (s.startsWith("depth ")) {
    depthPID.setpoint = s.substring(6).toFloat();
    pectoral.dive_offset = -15.0f;
    Serial.println("Diving...");
  }
  else if (s == "?") {
    Serial.println("Commands: status | throttle X(0-1) | depth X(m) | stop | go");
  }
}

// ============================================================
//  SETUP
// ============================================================
void setup() {
  Serial.begin(115200);
  Wire.begin(21, 22);
  Wire.setClock(400000);
  Serial.println("\n+--------------------------------------------------------------+");
  Serial.println("|  HAIFISCH-ROBOTER -- HYBRID PASSIVE TAIL v1.2             |");
  Serial.println("|  Branch: dev/hybrid-passive-tail                         |");
  Serial.println("|  2x AKTIV (J1/J2) + 2x PASSIV (J3/J4)                    |");
  Serial.println("|  Nockenwelle: 60mm, e=3mm | Getriebe: 40:1                |");
  Serial.println("+--------------------------------------------------------------+\n");
  motor_init();
  Serial.println("[OK] ESC PWM initialized (Pin 25)");
  mpu_init();
  Serial.println("[OK] MPU-6050 OK");
  ms5837_init();
  Serial.println("[OK] MS5837 OK");
  WiFi.softAP(WIFI_SSID, WIFI_PASS);
  udp.begin(4210);
  Serial.print("[OK] WiFi AP: "); Serial.print(WIFI_SSID);
  Serial.print(" | IP: "); Serial.println(WiFi.softAPIP());
  Serial.println("\n[Ready] Type '?' for commands.\n");
}

// ============================================================
//  MAIN LOOP
// ============================================================
void loop() {
  uint32_t now = millis();
  if (now - lastSensor >= SENSOR_DT_MS) {
    lastSensor = now;
    mpu_read();
    ms5837_read();
  }
  static uint32_t lastMotor = 0;
  if (now - lastMotor >= 10) {
    lastMotor = now;
    motor_update(0.01f);
  }
  updatePectoralFins();
  if (now - lastPID >= PID_DT_MS) {
    lastPID = now;
    runDepthPID((float)PID_DT_MS / 1000.0f);
  }
  if (now - lastTelem >= TELEM_DT_MS) {
    lastTelem = now;
    Serial.printf("[%lu] T:%.0f%% f:%.2fHz D:%.2fm P:%.1f deg\n",
                  now/1000, motor.throttle*100, motor.freq_swim, depthM, pitchDeg);
  }
  parseUDP();
  parseSerial();
  delay(5);
}

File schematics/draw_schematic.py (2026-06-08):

#!/usr/bin/env python3
"""
Vollständiger Punkt-zu-Punkt Schaltplan — Biomimetic Shark Robot
Jede Verbindung geht von einem konkreten Pin zu einem anderen Pin.
KiCad-ähnlicher Stil mit Power-Symbolen und Net-Labels.
"""

lines = []

def svg_start(w=1600, h=1000):
    lines.append(f'''<?xml version="1.0" encoding="UTF-8"?>
<svg xmlns="http://www.w3.org/2000/svg" width="{w}" height="{h}" viewBox="0 0 {w} {h}">
<style>
  * {{ font-family: "Courier New", monospace; }}
  .comp  {{ fill:#F0F4FF; stroke:#1133AA; stroke-width:1.5; }}
  .power {{ fill:#FFF0E8; stroke:#AA4400; stroke-width:1.5; }}
  .sensor{{ fill:#EFFFEF; stroke:#116611; stroke-width:1.5; }}
  .servo {{ fill:#FFF0FF; stroke:#881188; stroke-width:1.5; }}
  .motor {{ fill:#FFFAEE; stroke:#AA6600; stroke-width:1.5; }}
  .lbl   {{ font-size:12px; font-weight:bold; fill:#111; }}
  .pin   {{ font-size:9px; fill:#333; }}
  .net   {{ font-size:9px; fill:#0033AA; font-style:italic; }}
  .val   {{ font-size:8px; fill:#555; }}
  line.pwr  {{ stroke:#CC2222; stroke-width:1.8; fill:none; }}
  line.gndw {{ stroke:#226622; stroke-width:1.8; fill:none; }}
  line.bec  {{ stroke:#CC6600; stroke-width:1.8; fill:none; }}
  line.v33  {{ stroke:#EE8800; stroke-width:1.8; fill:none; }}
  line.sig  {{ stroke:#2255CC; stroke-width:1.5; fill:none; }}
  line.i2c  {{ stroke:#AA6600; stroke-width:1.5; fill:none; stroke-dasharray:6,3; }}
  line.mot  {{ stroke:#CC4400; stroke-width:2; fill:none; }}
  line.srv  {{ stroke:#881188; stroke-width:1.5; fill:none; }}
  circle.junc{{ fill:#222; stroke:none; }}
</style>
<rect width="{w}" height="{h}" fill="#FDFCF8"/>''')

def svg_end():
    lines.append('</svg>')

def rect(x, y, w, h, cls='comp', rx=4):
    lines.append(f'<rect x="{x}" y="{y}" width="{w}" height="{h}" class="{cls}" rx="{rx}"/>')

def text(x, y, txt, cls='lbl', anchor='middle', size=None):
    sattr = f' font-size="{size}px"' if size else ''
    lines.append(f'<text x="{x}" y="{y}" text-anchor="{anchor}" class="{cls}"{sattr}>{txt}</text>')

def line(x1, y1, x2, y2, cls='sig'):
    lines.append(f'<line x1="{x1}" y1="{y1}" x2="{x2}" y2="{y2}" class="{cls}"/>')

def wire(pts, cls='sig'):
    """Draw orthogonal wire through list of (x,y) points"""
    for i in range(len(pts)-1):
        line(pts[i][0], pts[i][1], pts[i+1][0], pts[i+1][1], cls)

def junc(x, y, r=4):
    lines.append(f'<circle cx="{x}" cy="{y}" r="{r}" class="junc"/>')

def gnd_sym(x, y, label='GND'):
    """GND symbol pointing down from pin (x,y)"""
    lines.append(f'''<g>
  <line x1="{x}" y1="{y}" x2="{x}" y2="{y+14}" class="gndw"/>
  <line x1="{x-12}" y1="{y+14}" x2="{x+12}" y2="{y+14}" class="gndw"/>
  <line x1="{x-7}"  y1="{y+20}" x2="{x+7}"  y2="{y+20}" class="gndw"/>
  <line x1="{x-3}"  y1="{y+26}" x2="{x+3}"  y2="{y+26}" class="gndw"/>
</g>''')

def vcc_sym(x, y, label='+5V', cls='bec'):
    """VCC symbol pointing up from pin (x,y)"""
    lines.append(f'''<g>
  <line x1="{x}" y1="{y}" x2="{x}" y2="{y-14}" class="{cls}"/>
  <line x1="{x-14}" y1="{y-14}" x2="{x+14}" y2="{y-14}" class="{cls}"/>
  <text x="{x}" y="{y-18}" text-anchor="middle" class="net" font-size="9">{label}</text>
</g>''')

def pin_stub(x, y, dx, label, cls='pin', anchor=None):
    """Draw a short pin stub and label"""
    x2 = x + dx
    line(x, y, x2, y, 'sig' if 'sig' not in cls else cls)
    anch = anchor or ('end' if dx < 0 else 'start')
    offset = -3 if dx < 0 else 3
    lines.append(f'<text x="{x2+offset}" y="{y+4}" text-anchor="{anch}" class="pin">{label}</text>')

def net_label(x, y, label, anchor='start'):
    lines.append(f'<rect x="{x-2}" y="{y-10}" width="{len(label)*7+4}" height="13" '
                 f'fill="white" stroke="#0033AA" stroke-width="0.5" rx="2"/>')
    lines.append(f'<text x="{x}" y="{y}" text-anchor="{anchor}" '
                 f'class="net" font-size="9">{label}</text>')

def box_comp(x, y, w, h, title, subtitle='', cls='comp'):
    rect(x, y, w, h, cls)
    text(x+w//2, y+16, title, 'lbl')
    if subtitle:
        text(x+w//2, y+28, subtitle, 'val')

# ════════════════════════════════════════════════════════════════════════
svg_start(1600, 1000)

# ────────────────────────────────────────────────────────────────────────
# KOMPONENTEN definieren (x, y, w, h)
# ────────────────────────────────────────────────────────────────────────

# 1. LiPo 3S  (40, 80, 90, 110)
LX,LY = 40, 80
box_comp(LX,LY,90,110,'LiPo 3S','11.1V 2200mAh','power')
text(LX+45, LY+45, 'XT60', 'val')
# Pins right side
# B+
LP_BPLUS = (LX+90, LY+30)
text(LP_BPLUS[0]-5, LP_BPLUS[1]+4, 'B+', 'pin', 'end')
# B-
LP_BMINUS = (LX+90, LY+80)
text(LP_BMINUS[0]-5, LP_BMINUS[1]+4, 'B−', 'pin', 'end')

# 2. ESC 20A  (200, 50, 160, 170)
EX,EY = 200, 50
box_comp(EX,EY,160,170,'ESC 20A','Hobbywing Platinum','comp')
text(EX+80, EY+43, 'BEC 5V/3A', 'val')
# Pins left
EP_VPLUS  = (EX,     EY+40)   # VIN+
EP_GNDIN  = (EX,     EY+70)   # GND in
EP_PWMIN  = (EX,     EY+130)  # PWM in
# Pins right
EP_BEC5V  = (EX+160, EY+40)   # BEC 5V out
EP_BECGND = (EX+160, EY+70)   # BEC GND
EP_PHA    = (EX+160, EY+100)  # Phase A
EP_PHB    = (EX+160, EY+120)  # Phase B
EP_PHC    = (EX+160, EY+140)  # Phase C

for (px,py),lbl in [(EP_VPLUS,'VIN+'),(EP_GNDIN,'GND'),(EP_PWMIN,'PWM IN')]:
    lines.append(f'<line x1="{px}" y1="{py}" x2="{px-18}" y2="{py}" class="sig"/>')
    lines.append(f'<text x="{px-20}" y="{py+4}" text-anchor="end" class="pin">{lbl}</text>')
for (px,py),lbl in [(EP_BEC5V,'BEC 5V'),(EP_BECGND,'BEC GND'),
                     (EP_PHA,'Ph A'),(EP_PHB,'Ph B'),(EP_PHC,'Ph C')]:
    lines.append(f'<line x1="{px}" y1="{py}" x2="{px+18}" y2="{py}" class="sig"/>')
    lines.append(f'<text x="{px+20}" y="{py+4}" text-anchor="start" class="pin">{lbl}</text>')

# 3. BL Motor  (500, 60, 130, 100)
MX,MY = 500, 60
box_comp(MX,MY,130,100,'BL Motor','KV=900 Outrunner','motor')
text(MX+65, MY+55, 'Getriebe 40:1', 'val')
MP_PHA = (MX, MY+30)
MP_PHB = (MX, MY+50)
MP_PHC = (MX, MY+70)
for (px,py),lbl in [(MP_PHA,'Ph A'),(MP_PHB,'Ph B'),(MP_PHC,'Ph C')]:
    lines.append(f'<line x1="{px}" y1="{py}" x2="{px-18}" y2="{py}" class="mot"/>')
    lines.append(f'<text x="{px-20}" y="{py+4}" text-anchor="end" class="pin">{lbl}</text>')
# Shaft out right
lines.append(f'<line x1="{MX+130}" y1="{MY+50}" x2="{MX+165}" y2="{MY+50}" stroke="#666" stroke-width="3" fill="none"/>')
text(MX+170, MY+46, '→ Nocken- welle', 'val', 'start', 8)
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

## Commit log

2026-06-04 Initial commit: Biomimetic Shark Robot - Single Brushless Motor Edition
    - Complete ESP32 firmware with single-motor control
    - Eccentric cam kinematics simulator (Python)
    - Full mechanical documentation (single motor + cam system)
    - Hydrodynamic optimization tools
    - Silicone molding guide for realistic fins
    - 3D print specifications for all parts
    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
2026-06-04 Add CAD files, STL models, CNC G-Code, Schematics & BOM
    3D-Print STL Files (13 parts):
    - body_front.stl (Hauptelektronikgehäuse, Ø80mm)
    - body_lid_oring.stl (Deckel mit O-Ring-Nut)
    - servo_mount_j1.stl (Servo-Halter Gelenk J1)
    - tail_link_j2.stl (Gelenk-Verbinder J2)
    - tail_link_j3_passive.stl (Passives Federgelenk J3, TPU)
    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
    [ballast_syringe_holder.stl, body_front.scad, body_front.stl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]
2026-06-07 Add complete Fritzing schematic + full SVG wiring diagram
    schematics/shark_robot_schematic.fzz:
    - Fritzing-kompatible .fzz Datei (ZIP-Format)
    - Vollständige Netzliste (13 Netze)
    - Alle Verbindungen korrekt verdrahtet:
    * LiPo 3S → ESC VIN (11.1V)
    * ESC BEC 5V → ESP32/PCA9685/Servos
    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
    [shark_robot_schematic.fzz]
2026-06-08 Fix schematic: vollständige point-to-point Verdrahtung
    Alle Verbindungen sind jetzt explizit von Pin zu Pin gezeichnet:
    Neue Verbindungen (26 Netze, alle verdrahtet):
    1. LiPo B+ → ESC VIN+
    2. LiPo B- → ESC GND_IN (via GND Bus)
    3. ESC Phase A → BL Motor Phase A
    4. ESC Phase B → BL Motor Phase B
    5. ESC Phase C → BL Motor Phase C
    6. ESC BEC 5V → ESP32 VIN
    7. ESC BEC 5V → PCA9685 VCC (junction)
    8. ESC BEC 5V → Servo BFL/BFR/BAL VCC (junction)
    9. ESC BEC GND → GND Bus
    10. ESP32 GND → GND Bus
    11. PCA9685 GND → GND Bus
    12. MS5837 GND → GND Bus
    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
    [shark_robot_schematic.fzz]
2026-06-08 Add RF underwater physics, visualisation & tether firmware
    docs/rf_underwater/rf_physics.md:
    - Physikalische Grundlagen (Skin-Tiefe Formel + Herleitung)
    - Frequenz-Vergleichstabelle für alle relevanten Frequenzen
    - Wassertypen (Süss/Brack/Meer) mit ρ und σ-Werten
    - Quantitative Analyse: 433 MHz = −36dB bei 1m → unbrauchbar
    - Lösungsoptionen mit Bewertung (Tether/27MHz/Hybrid/Akustisch)
    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
2026-06-08 Add complete technical drawing (SVG visual documentation)
    docs/technical_drawing.svg — Vollständige Konstruktionszeichnung 1200×900px:
    A) Seitenriss (1:3)
    - Vollständige Haifisch-Silhouette mit realistischen Kurven
    - Rücken- und Brustflossen
    - Lunate Schwanzflosse
    - Gelenke J1–J4 sichtbar mit Achspunkten
    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
2026-06-16 fix: grammar corrections in cad/STEP_CONVERSION_NOTE.md
2026-06-16 fix: grammar corrections in cad/stl/STEP_CONVERSION_NOTE.md
2026-06-16 Redesign: Switch to variable lever arm system for progressive joint amplitudes
    - Standard exzentrische Nockenwelle (e=3mm, günstiger!)
    - Variable Hebelarm-Längen an jedem Gelenk
    - Progressive Amplituden: ±11° → ±27° (biologisch authentisch)
    - Vereinfachte Fertigung und höhere Flexibilität
    - Aktualisierte Dokumentation und Kostenkalkulation
2026-06-16 Update: 3D print documentation for variable lever arm design with 4 different joint flanges
2026-06-17 fix: variable lever lengths per joint (J1=30, J2=25, J3=18, J4=12mm)
2026-06-17 fix: correct amplitudes arcsin(e/L), update lever arm specs J1-J4
2026-06-17 fix: BOM updated for variable lever arm design (J1-J4 flanges, Nockenwelle 35 CHF)
    [bom_complete.csv]
2026-06-17 fix: update comments for variable lever arm design (J1-J4), v1.1
    [shark_single_motor_firmware.ino]
2026-06-18 feat: hybrid kinematik — J1/J2 active, J3/J4 passive TPU spring simulation
2026-06-18 feat: 3D print structure for hybrid design — TPU passive joints J3/J4
2026-06-18 feat: BOM for hybrid design — short camshaft 60mm, TPU joints J3/J4, -20 CHF
    [bom_complete.csv]
2026-06-18 feat: OpenSCAD parametric source for tpu_joint_j3.scad
    [tpu_joint_j3.scad]
2026-06-18 feat: OpenSCAD parametric source for tpu_joint_j4.scad
    [tpu_joint_j4.scad]
2026-06-18 feat: OpenSCAD parametric source for tail_link_parametric.scad
    [tail_link_parametric.scad]
2026-06-19 feat: OpenSCAD connector flange between shark hull and J1 joint
    [body_to_j1_flange.scad]
2026-06-19 fix: update README.md to hybrid design — correct amplitudes + passive J3/J4
2026-06-19 fix: update mechanics/single_motor_mechanics.md to hybrid design — correct amplitudes + passive J3/J4
2026-06-19 chore: remove outdated cad/stl/tail_link_j3_passive.stl (replaced by tpu_joint_j3.scad)
    [tail_link_j3_passive.stl]
2026-06-19 chore: remove outdated cad/tail_link_j3_passive.stl (replaced by tpu_joint_j3.scad)
    [tail_link_j3_passive.stl]
2026-06-19 feat: nocke_kinematik.py — hybrid passive tail v1.2 (Strouhal, amplitude analysis)
2026-06-19 feat: shark_single_motor_firmware.ino — hybrid passive tail v1.2 (Strouhal, amplitude analysis)
2026-06-19 docs: add acknowledgements — OpenFish (CC-BY-SA 4.0) + FISHR (CC BY 4.0)
2026-06-23 fix: mirror workflow — check before create, --force push, consistent secrets
2026-06-23 feat: issue sync workflow GitHub → Codeberg
2026-06-23 feat: issue sync script — labels, comments, status (Stufe 2)
